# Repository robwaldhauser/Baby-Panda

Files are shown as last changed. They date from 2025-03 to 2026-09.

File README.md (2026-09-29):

# Baby-Panda 🐼
#### CoreXY Continuous Printing

Baby Panda is a CoreXY printer with conveyor build plate to enable affordable high quality continuous printing. The motion system is based on the [Voron 2.4](https://vorondesign.com/voron2.4), with z motor mounts and skirts modified to accommodate the conveyor.  The design is intended to repurpose as many parts as possible from a pair of Ender 3s.

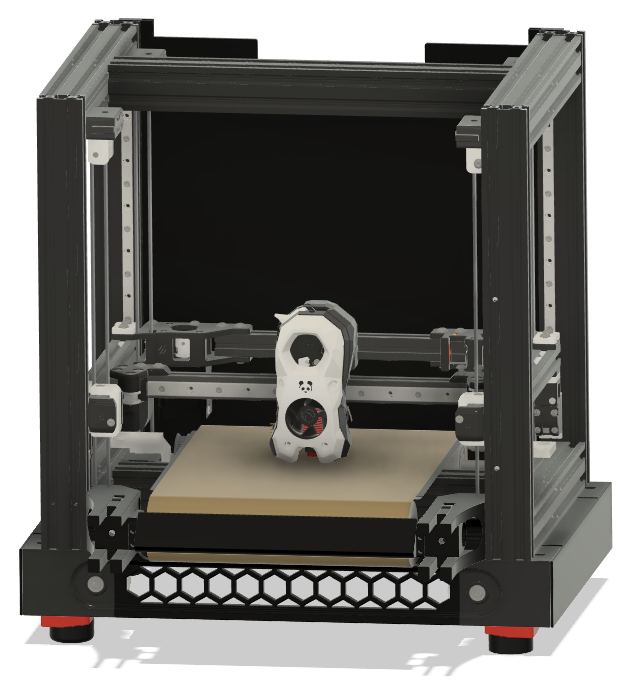
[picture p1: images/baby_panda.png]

If you like this project, please consider <a href="https://www.ko-fi.com/robxberty">tipping</a>!
## Building Baby Panda
There are currently no build instructions specific to Baby Panda, so but the [Voron 2.4r2 assembly manual](https://github.com/VoronDesign/Voron-2/raw/Voron2.4/Manual/Assembly_Manual_2.4r2.pdf) can be used for the most part, along with the following reasources for the Baby Panda-specific parts:
* [BOM](https://github.com/robwaldhauser/Baby-Panda/blob/main/BOM%20Spreadsheet.ods) - Baby Panda bill of materials (.ods format)
* [STLs](https://github.com/robwaldhauser/Baby-Panda/tree/main/STLs) - model files for each part
* [CAD](https://github.com/robwaldhauser/Baby-Panda/tree/main/CAD) - An archive containing a .step file with a fully assembled Baby Panda

If you have any questions, or want to see pictures and videos of builds, check out the #🐼baby-panda channel in the [Build Biome Discord server](https://discord.gg/SpCVg9wG). 

## Ender 3 Parts Reuse
As mentioned above, one of the goals of this project is to repurpose parts from Ender 3s that are sitting around gathering dust. Some of the parts that can be reused include:
* All base 4040 extrusions (Pro/V2)
* Y 4040 extrusion (Pro\*)
* 4020 extrusions (Pro/V2)
* Power supply
* Mainboards\**
* Motors
* Bed carriage
* Heated bed
* Some wiring

\*V2 Y 4040 extrusion could be reused with spacers
\*\*A total of 8 motors drivers are needed, but if you have 2 mainboards they can both be used

## The Belt Assembly
This assembly is the heart of the project. It adds one additional stepper motor to the BOM. There is nothing official released yet, but several people in the Discord are working on macros to make it work. The purpose of the belt is to eject printed parts automatically after printing so that another job can run immediately and without intervention. It is not intended to move during a print as X-Y movement is handled by the coreXY motion system.
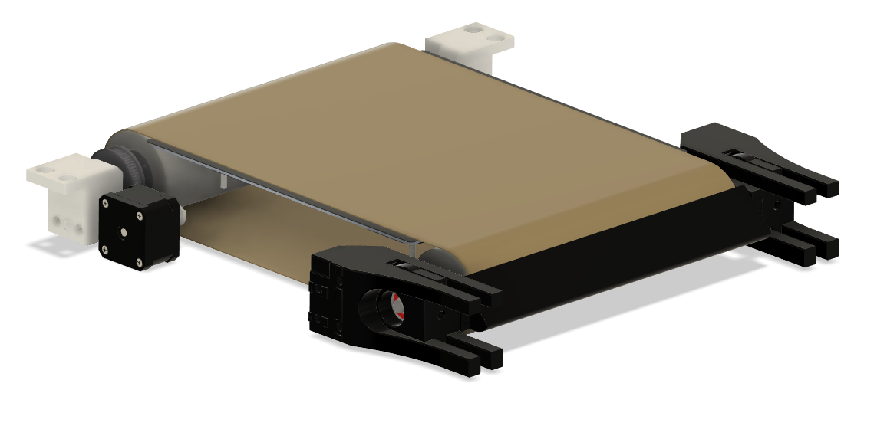
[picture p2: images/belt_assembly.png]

<p><em>Belt assembly</em></p>

### Belt Cart Mod

An optional redesign of the belt assembly by [@3DCreationsByChad](https://github.com/3DCreationsByChad) that makes the whole belt a **removable cartridge** — rollers, rods, bearings and drive motors lift out as one unit, so belt and bed maintenance no longer means dismantling the machine. It also **fixes the bed sag** present in the original design.

Parts, hardware, print settings and frame preparation: **[BeltCartMod/](BeltCartMod/)**

⚠️ It is not compatible with the old bed shield, and it requires new through-holes drilled in the frame sides for the dual bed rails. A printable drill jig is included.

## The Frame
The standard Baby Panda frame can be built entirely from extrusions salvaged from 2 Ender 3s. Ender 3 pro is ideal. 3V2 can work, but the Y extrusion is slightly shorter. This can be worked around using spacers or by buying a longer extrusion.

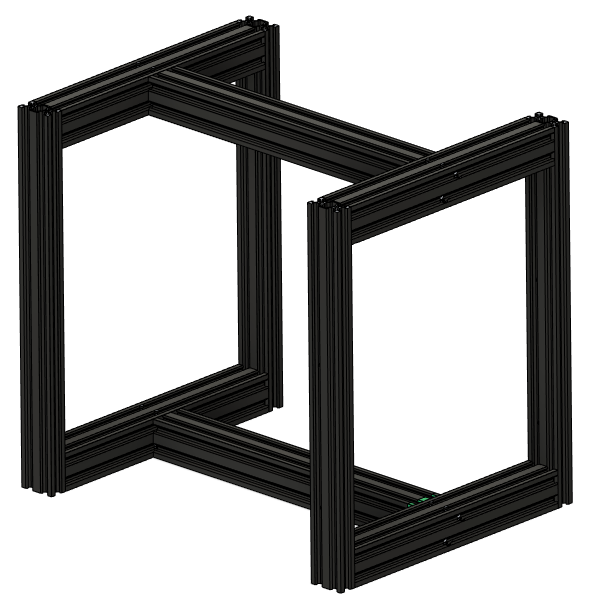
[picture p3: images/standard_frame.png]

<p><em>Standard frame</em></p>

<p>In the standard configuration, the 3 4040 extrusions from the base of one Ender form the base of the Baby Panda frame, and the base extrusions of the other Ender  form the top. The uprights from each ender, which will need to be drilled out for blind joints using the <a href="https://github.com/robwaldhauser/Baby-Panda/blob/main/STLs/Drilling%20Jig.stl">jig</a> available in the CAD section, connect the top of the frame to the bottom in each corner. In case you're not familiar with drilling/tapping new blind joints, <a href="https://www.youtube.com/watch?v=2dvbn0rWA60&ab_channel=CanuckCreator">this video</a> is really helpful. Optionally, 2 additional 2020 extrusions can be installed for extra rigidity and to help enclose the printer.</p>

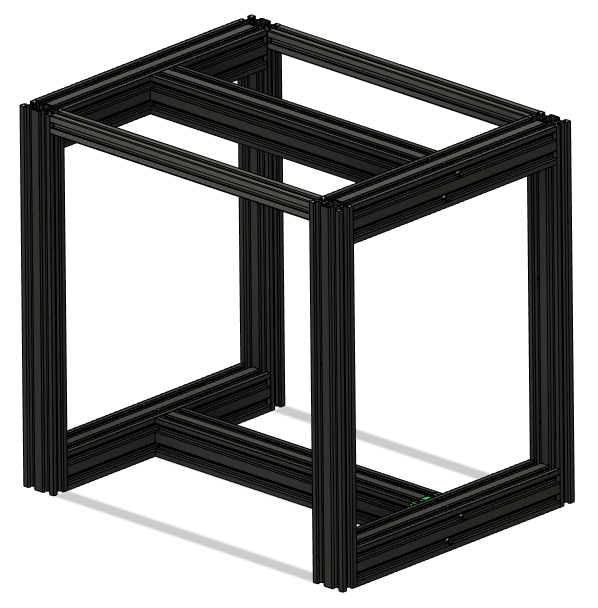
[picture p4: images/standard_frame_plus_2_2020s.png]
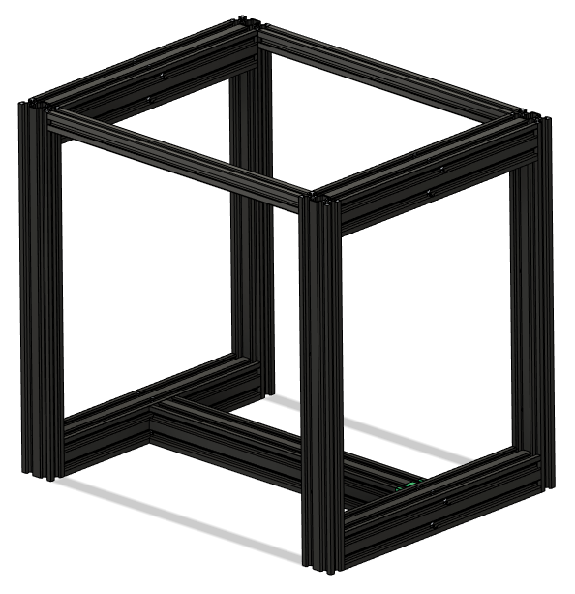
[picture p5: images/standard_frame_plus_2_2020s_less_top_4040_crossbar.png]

<p><em>A couple options for placement of additional 2020 extrusions</em></p>

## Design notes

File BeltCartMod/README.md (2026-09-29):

# Belt Cart Mod

A removable belt cartridge for Baby Panda. The whole belt assembly — rollers, rods,
bearings and drive motors — lifts out of the printer as one unit, so belt and bed
maintenance no longer means dismantling the machine.

Designed by **Chad Deitrich** ([@3DCreationsByChad](https://github.com/3DCreationsByChad)).

## Why

Two things it fixes:

1. **Tool-less service.** The roller holders stay tight to the belt, so the cartridge
   slides out without disassembly. Bed maintenance is four bolts a side.
2. **It fixes the bed sag** present in the original design.

## Printed parts

All eight are new. Print one of each — the left and right files are true mirrors,
not copies.

| Part | Qty | Size (mm) | Volume |
|---|---|---|---|
| `belt_cart_mod_adjustable_belt_motor_mount` L + R | 2 | 38 × 68.6 × 52 | 28.9 cm³ ea |
| `front_roller_arm_toolless_frame-side_part_1_front` L + R | 2 | 60 × 74.2 × 58.3 | 150.4 cm³ ea |
| `front_roller_arm_toolless_roller-side_part_2_front` L + R | 2 | 60 × 168.1 × 50.2 | 158.3 cm³ ea |
| `rear_bearing_holder_tool-less` L + R | 2 | 20 × 121.8 × 52 | 49.1 cm³ ea |
| `Baby_Panda_cart_mod_drill_jig` (tool, not part of the printer) | 1 | 55 × 80 × 55.8 | 101.8 cm³ |

**Material: roughly 442 g** for the eight parts at a typical 4-wall / 25% infill
(982 g if printed solid), plus ~130 g for the jig.

**Print settings: Voron standard.**

### Reused from the original design

The mod does **not** replace these — keep the ones you have:

- Front bearing holders (old style, L + R)
- Front and rear rollers

## Hardware

| Item | Spec |
|---|---|
| Front arms | 4 × M3×15 socket head screws + 4 × M3 heat-set inserts |
| Motor mounts | 4 screws with shims per mount |
| Frame / bed rail bolts | **M6 socket head cap screws** |
| Rods, front and rear | Ø8 × 300 mm |
| Rollers, front and rear | Ø57 × 230 mm |
| Bearings | 608 skateboard bearings (8 mm bore) |
| Drive motors | 2 × **salvaged stock Ender 3 NEMA 17** (5 mm shaft) |
| Bed rails | **2 × 4040 × 350 mm extrusion** (4020/2040 works, 4040 is better) |
| Drive belt | GT2 closed loop, **200 mm × 6 mm** — 2 needed |
| Motor pulley | GT2 **20 tooth, 5 mm bore** — 2 needed |
| Roller pulley | GT2 **60 tooth, 8 mm bore** — 2 needed (3:1 reduction) |

**You need two of each size**, one per side.

⚠️ **The two pulleys take different bores.** The motors are salvaged stock Ender 3
steppers, which have **5 mm shafts**, so the 20T is a **5 mm bore**. The 60T mounts on
the Ø8 roller rod, so it is an **8 mm bore**. Many GT2 kits ship both sizes at a single
bore — check before you buy.

The 200 mm belt is corroborated by the CAD: measured centre distance between the motor
and roller pulleys is **56.87 mm**, which with 20T (Ø12.73 pitch) and 60T (Ø38.20 pitch)
gives a required belt of **196.6 mm**. The 3.4 mm difference is taken up by the
*adjustable* motor mount as tension.

## Frame preparation

⚠️ **This mod requires drilling new through-holes in the sides of the frame** to mount
the dual bed rails.

Hole spec, from the counterbore drill used:

- **Through-hole: 6.5 mm**
- **Counterbore: 10 mm diameter × 13 mm deep**, to seat the M6 socket head

A printable drill jig is included (`Baby_Panda_cart_mod_drill_jig`). Measured features:

| Feature | Axis | Pattern |
|---|---|---|
| Ø9.60 × 4 | X | 20.00 × 19.80 mm rectangle |
| Ø5.20 × 2 (with Ø11.40 counterbore) | Z | 20.00 mm apart |
| Ø6.00 × 2 | Y | 50.80 mm apart |
| Ø6.40 × 2 | Y | 49.40 mm apart |

A step drill of the `HSS 10×6.5×13` type with a depth-stop collar cuts the through-hole
and the head cavity in one operation. ⚠️ The jig and that drill are **untested together**
— the original holes were marked and drilled freehand on a drill press.

## ⚠️ Compatibility

- **Not compatible with the old bed shield.**
- Requires new through-holes in the frame sides (above).
- Bed rails must be 4020/2040 minimum; 4040 recommended.

## Files

- `STEP/` — source geometry, one file per part
- `STLs/` — ready to slice

All eight printed parts and the jig were verified as single valid solids
(`BRepCheck_Analyzer`), and each left/right pair matches its mirror exactly in
bounding box and volume.

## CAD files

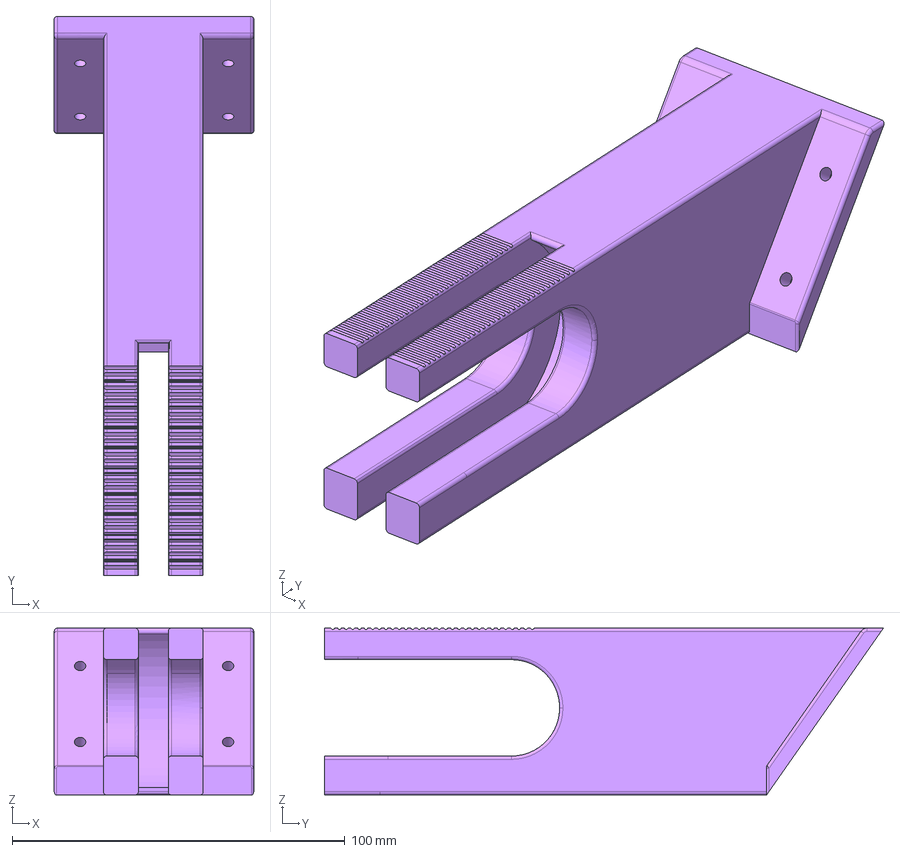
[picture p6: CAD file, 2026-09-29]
BeltCartMod/STEP/front_roller_arm_toolless_roller-side_part_2_front_left.step
60.0 x 168.1 x 50.2 mm

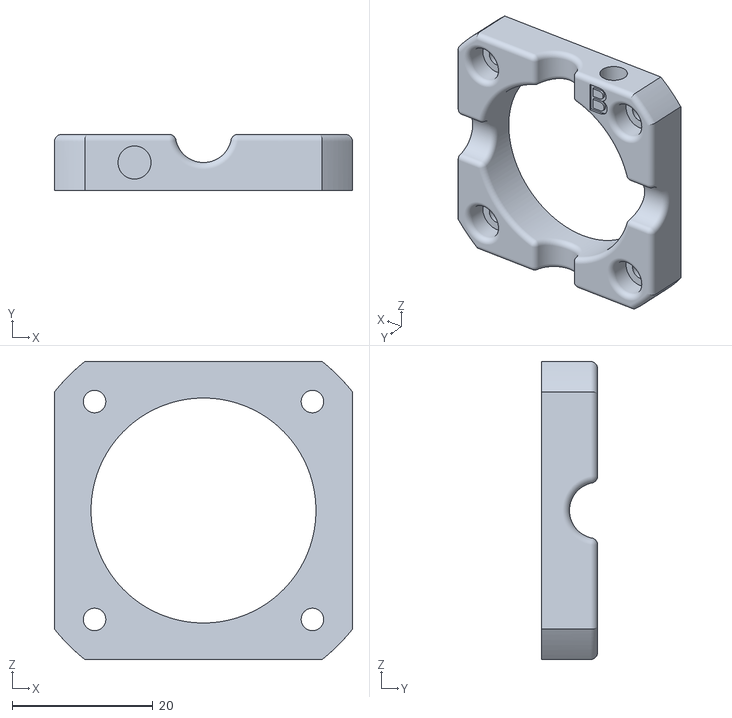
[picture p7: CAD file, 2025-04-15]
STLs/Z_Drive/BP_z_motor_mount_b_x2.stl
42.4 x 8.00 x 42.4

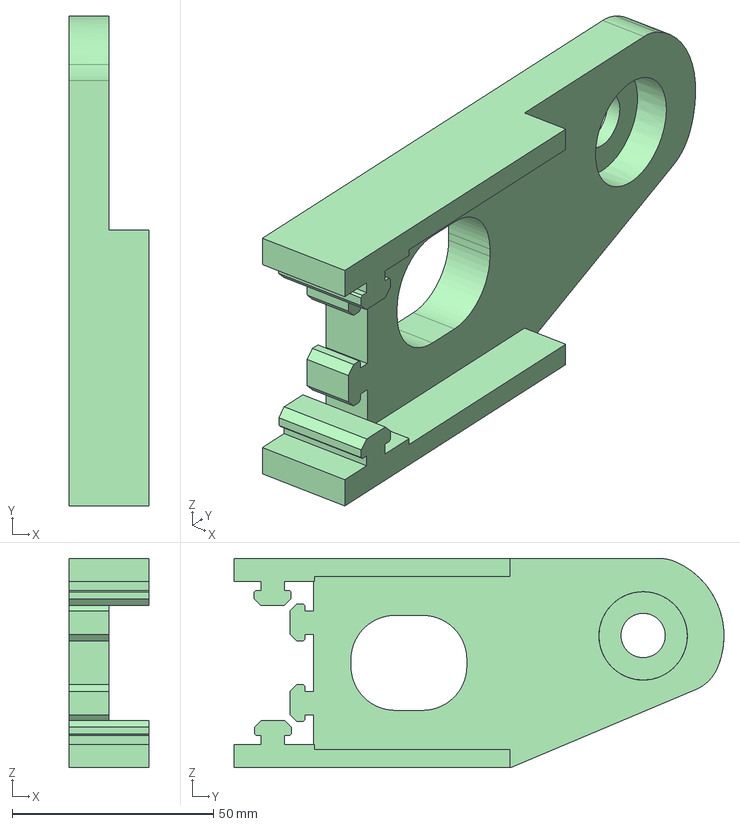
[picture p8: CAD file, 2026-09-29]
BeltCartMod/STEP/rear_bearing_holder_tool-less_right.step
20.0 x 121.7 x 52.0 mm

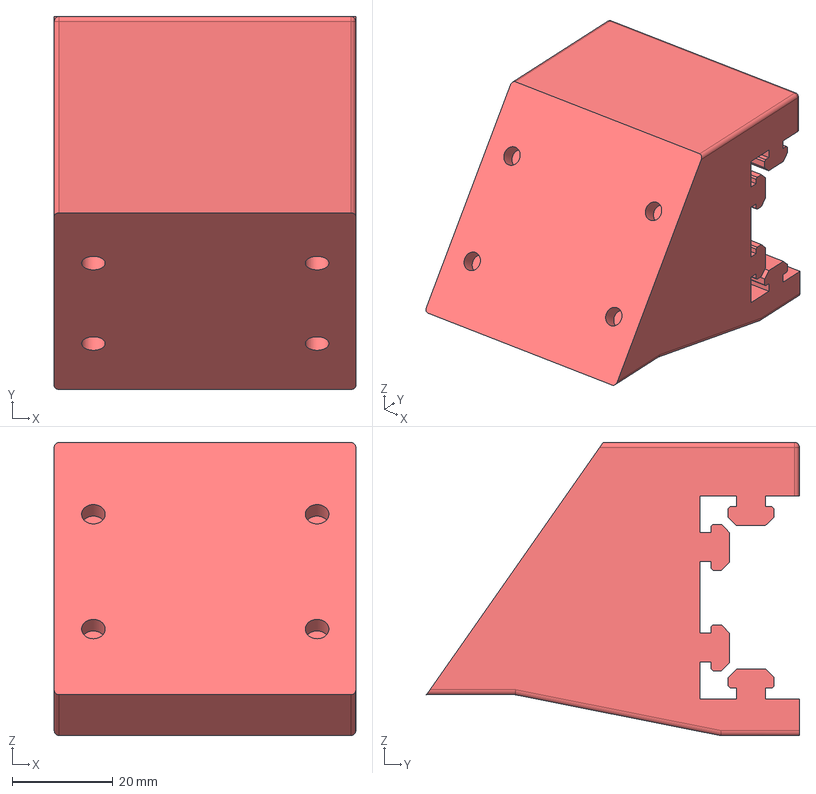
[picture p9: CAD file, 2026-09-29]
BeltCartMod/STEP/front_roller_arm_toolless_frame-side_part_1_front_left.step
60.0 x 74.2 x 58.3 mm

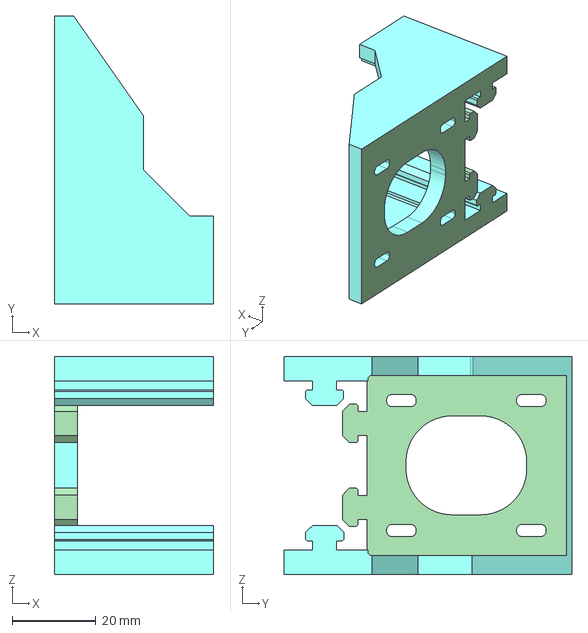
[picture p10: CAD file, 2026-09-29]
BeltCartMod/STEP/belt_cart_mod_adjustable_belt_motor_mount_right.step
38.0 x 68.6 x 52.0 mm

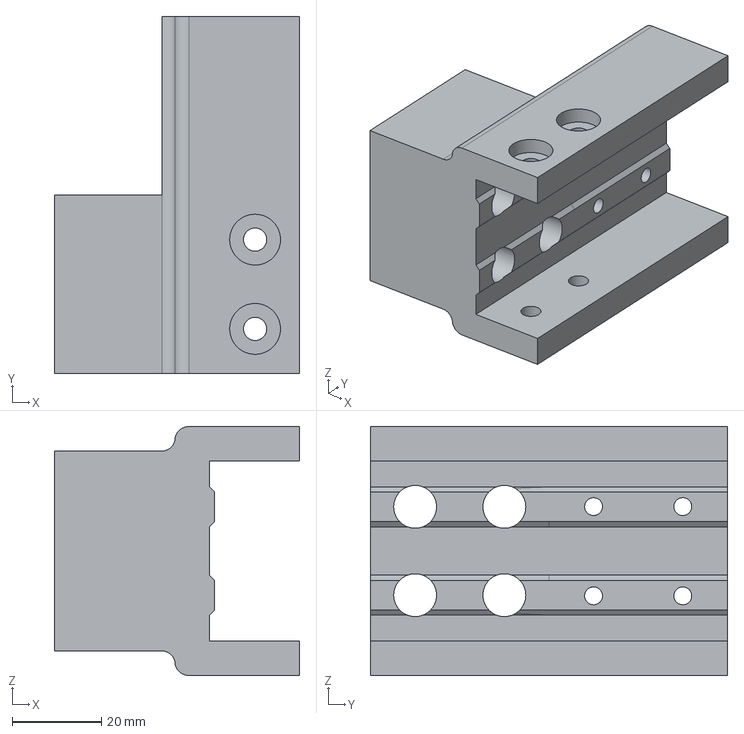
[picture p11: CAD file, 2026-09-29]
BeltCartMod/STEP/Baby_Panda_cart_mod_drill_jig.step
55.0 x 80.0 x 55.8 mm

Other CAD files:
STLs/Z_Drive/BP_z_motor_mount_a_x2.stl
BeltCartMod/STEP/front_roller_arm_toolless_roller-side_part_2_front_right.step
BeltCartMod/STEP/rear_bearing_holder_tool-less_left.step
BeltCartMod/STEP/front_roller_arm_toolless_frame-side_part_1_front_right.step
BeltCartMod/STEP/belt_cart_mod_adjustable_belt_motor_mount_left.step
BeltCartMod/STLs/Baby_Panda_cart_mod_drill_jig.stl
BeltCartMod/STLs/belt_cart_mod_adjustable_belt_motor_mount_left.stl
BeltCartMod/STLs/belt_cart_mod_adjustable_belt_motor_mount_right.stl
BeltCartMod/STLs/front_roller_arm_toolless_frame-side_part_1_front_left.stl
BeltCartMod/STLs/front_roller_arm_toolless_frame-side_part_1_front_right.stl
BeltCartMod/STLs/front_roller_arm_toolless_roller-side_part_2_front_left.stl
BeltCartMod/STLs/front_roller_arm_toolless_roller-side_part_2_front_right.stl
BeltCartMod/STLs/rear_bearing_holder_tool-less_left.stl
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

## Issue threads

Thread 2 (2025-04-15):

Motor mount can interfere with the ability to tighten grub screws on pulley that drives z belts

BildermanKawasaki, 2025-04-15:
The pulley can end up with the grub screws partially blocked by the motor mount so that either you have to use a ball end wrench or fight binding trying to get the hex wrench out after the grub screw is tight.
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

Suggest creating a small channel/opening in the motor mount to allow better grub screw access.

An example is the [transmission from Kevinakasam's belt z](https://github.com/kevinakasam/BeltDrivenEnder3/blob/main/V3/Single_Z/1_Transmission_V3.7.stl), which has channels for the grub screws on both the 80T gear and the 20T pulley.

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

Closed 2025-04-15.

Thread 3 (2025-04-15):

Z motors missing from CAD

BildermanKawasaki, 2025-04-15:
It would be great to have Z motors shown in cad for several reasons:

- Clearly show which way the connector faces
- Reference for what hardware to use both now, and when compiling an official BOM

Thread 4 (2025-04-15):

Lower cross member for bottom panels is marginal for Ender size bed

BildermanKawasaki, 2025-04-15:
If the [lower cross member] https://github.com/robwaldhauser/Baby-Panda/blob/main/STLs/Panels/Bottom%20Panels/Lower%20Crossmember.stl were trimmed by even 2-3mm on the diagonals on each corner it would be more foolproof to print from a 235x235mm bed without impacting performance. As is it's right up to the edge meaning people may have problems if their x/y offsets are even a little off.

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

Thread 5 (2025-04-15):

Motor mount heatsets pulling out

BildermanKawasaki, 2025-04-15:
After test fitting the motor and motor mount in the z drive I found that all 3 heatsets had pulled out about 0.5mm.

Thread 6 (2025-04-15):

Bottom panels including crossmember missing hardware

BildermanKawasaki, 2025-04-15:
CAD has no hardware for the bottom panels. I'm assuming 4 m5 screws and T-nuts for the panels on the built in standoffs and the same for the crossmember attaching to the frame. Then it seems like 4 short M3s to secure inside corners of each panel to M3 heatsets in the middle of the crossmember. I can say for sure the M5s have to be less than 10mm because that's the smallest the Voron hardware kit had and that's too long because it bottoms out in the V slot before the nut gets tight.

BildermanKawasaki, 2025-04-15:
M5x8 should work great for the panels (based on measurement I just took)

BildermanKawasaki, 2025-04-15:
M3x6 seemed fine for the crossmember to panel connection

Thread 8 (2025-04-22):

Z Drive Main Body Motor Mount Holes Too Small

BildermanKawasaki, 2025-04-22:
Slotted holes on main Z drive body aren’t wide enough to accommodate M3x6x1mm washer or deep enough for washer without SHCS head sticking up proud of the z drive body and interfering with The piece the foot mounts to. Photo shows screw heads protruding (washers were filed down on opposite sides to fit in slotted hole)

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

BildermanKawasaki, 2025-04-24:
BHCS screw solves the height clearance problem.

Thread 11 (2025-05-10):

Electronics mounting missing

BildermanKawasaki, 2025-05-10:
Would be good to have a default electronics mounting setup modelled up, ideally with different mainboard options.

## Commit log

2025-04-15 updated BP_z_motor_mount_a+b
    updated BP_z_motor_mount_a+b to have better grub screw access. Also embossed A and B to each face to help distinguish between them
    [BP_z_motor_mount_a_x2.stl, BP_z_motor_mount_b_x2.stl]
2026-08-14 feat(belt-cart-mod): add removable belt cartridge parts, jig and docs
    Adds the belt cart mod as BeltCartMod/ — a redesign of the belt assembly
    that turns it into a removable cartridge. Rollers, rods, bearings and drive
    motors lift out as one unit, so belt and bed maintenance no longer requires
    dismantling the machine. It also fixes the bed sag present in the original
    design.
    Contents:
    - 8 printed parts (4 mirrored pairs) as STEP and STL
    - printable drill jig for the frame through-holes
    - README with parts table, hardware BOM, print settings and frame prep
    Every part was verified as a single valid solid with BRepCheck_Analyzer, and
    each left/right pair matches its mirror exactly in boundi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
    [Baby_Panda_cart_mod_drill_jig.step, Baby_Panda_cart_mod_drill_jig.stl, belt_cart_mod_adjustable_belt_motor_mount_left.step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]
2026-08-14 fix(belt-cart-mod): correct pulley bores — 20T is 5 mm, 60T is 8 mm
    The drive motors are salvaged stock Ender 3 steppers, which have 5 mm
    shafts. The 20T motor pulley is therefore a 5 mm bore, not 8 mm. The 60T
    mounts on the Ø8 roller rod and stays an 8 mm bore.
    This matters because many GT2 kits ship both tooth counts at a single bore,
    which would leave the 20T unable to mount. The README now states the two
    bores separately and warns about it.
    Also replaces the "32 mm body" motor note with the part that actually
    identifies it for sourcing: a salvaged stock Ender 3 NEMA 17.
